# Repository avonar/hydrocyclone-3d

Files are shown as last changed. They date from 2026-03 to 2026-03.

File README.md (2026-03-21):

# Hydrocyclone Prototype

This repository contains a parametric `OpenSCAD` prototype of a small household hydrocyclone / centrifugal sand separator intended as a pre-filter for well water.

The current concept is aimed at:

- `1-3 m^3/h` operating range, with `2.5 m^3/h` as the main design point
- `2-4 bar` system pressure
- `32 mm` external pipe connections
- sand and coarse suspended solids removal before a downstream filter

This is a geometry and assembly prototype, not a certified pressure vessel.

## Design Intent

The project is based on a hybrid engineering model:

- the upper part behaves like a compact hydrocyclone
- the lower part is treated as a straight underflow outlet for connection to a separate sediment collector / purge volume

Current base proportions:

- cyclone chamber diameter `Dc = 40 mm`
- cylindrical section height `Hc = 40 mm`
- cone length `Lc = 120 mm`
- vortex finder inner diameter `Do = 14 mm`
- lower outlet diameter `Du = 9 mm`
- minimum wall thickness `t = 4 mm`

The inlet is modeled as:

- external round `32 mm` stub
- internal transition to a short tangential slot

The top assembly is split into two printable parts:

- main body
- removable lid/head with the outlet stub and internal vortex finder

This split reduces support material and makes the upper internal geometry printable.

## Repository Layout

- [hydrocyclone_concept.scad](/Users/avonar/petprojects/hydrocyclone_v2/hydrocyclone_concept.scad)  
  Main source of truth for the current 3D geometry.

- [hydrocyclone_inlet_vertical_section_debug.scad](/Users/avonar/petprojects/hydrocyclone_v2/hydrocyclone_inlet_vertical_section_debug.scad)  
  Validation cut through the inlet plane. Useful for checking the inlet window and vortex finder depth relationship.

- [hydrocyclone_lid_section_debug.scad](/Users/avonar/petprojects/hydrocyclone_v2/hydrocyclone_lid_section_debug.scad)  
  Validation cut for the removable lid and inner outlet tube.

- [Makefile](/Users/avonar/petprojects/hydrocyclone_v2/Makefile)  
  Rebuilds printable artifacts and debug sections.

Generated files are written into `artifacts/`.

## Build

Requirements:

- `openscad`
- `magick` (ImageMagick) for `svg -> png` conversion

Common commands:

```bash
make -j all
```

Builds:

- body `STL`
- lid `STL`
- body `3MF`
- lid `3MF`
- assembly preview `STL`
- validation section `SVG` and `PNG` files

Other useful targets:

```bash
make -j prints
make -j validate
make preview
make print3mf
make clean
```

`Makefile` is intentionally structured so that `make -j ...` can run independent OpenSCAD renders in parallel.

## Current Outputs

After a successful build, the main outputs are:

- `artifacts/hydrocyclone_body_print.stl`
- `artifacts/hydrocyclone_lid_print.stl`
- `artifacts/hydrocyclone_body_print.3mf`
- `artifacts/hydrocyclone_lid_print.3mf`
- `artifacts/hydrocyclone_concept_preview.stl`

Validation outputs:

- `artifacts/hydrocyclone_inlet_vertical_section_debug.svg`
- `artifacts/hydrocyclone_inlet_vertical_section_debug.png`
- `artifacts/hydrocyclone_lid_section_debug.svg`
- `artifacts/hydrocyclone_lid_section_debug.png`

## Notes On Validation

Two validation cuts are kept in the repository on purpose:

- inlet section: checks whether the vortex finder extends low enough relative to the inlet opening
- lid section: checks whether the inner outlet tube is actually supported by the lid geometry

These are the two checks that are most likely to catch future geometry regressions.

## Safety

This model should be treated as a prototype for:

- fit checks
- printability checks
- assembly checks
- early hydraulic layout validation

It should not be treated as a production-ready pressurized component without:

- material verification
- wall / joint verification
- sealing design validation
- hydrostatic testing
- safety margin review

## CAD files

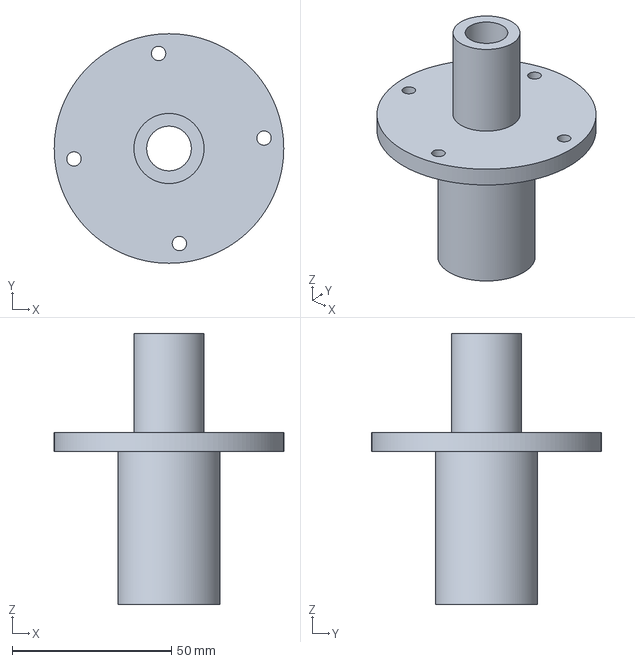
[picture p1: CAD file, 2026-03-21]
artifacts/hydrocyclone_lid_print.3mf
72.0 x 72.0 x 85.0 mm

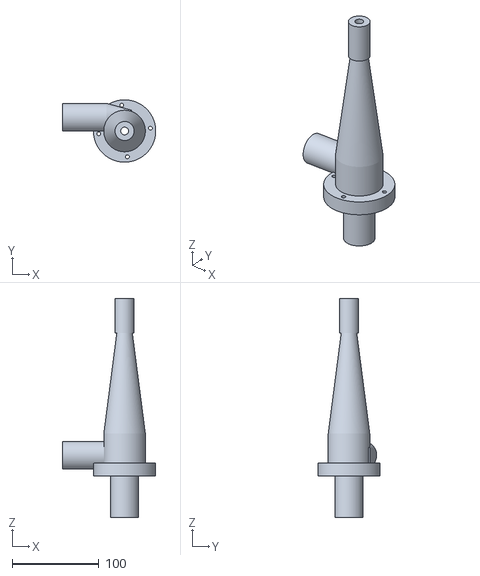
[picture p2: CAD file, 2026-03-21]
artifacts/hydrocyclone_concept_preview.stl
108.0 x 72.0 x 253.0

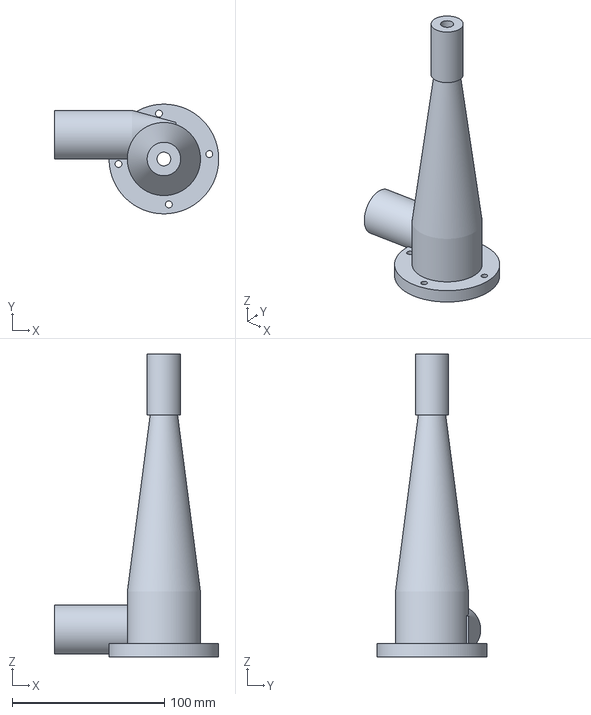
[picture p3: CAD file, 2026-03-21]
artifacts/hydrocyclone_body_print.3mf
108.0 x 72.0 x 199.0 mm

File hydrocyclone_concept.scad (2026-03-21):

$fn = 128;
render_mode = is_undef(render_mode) ? "assembly" : render_mode;

// Parametric hydrocyclone concept for layout and 3D-print iteration.
// Units: millimeters.
// This is a geometry study model, not a certified pressure vessel.

dc = 40; // Inner diameter of cylindrical vortex chamber
hc = 40; // Height of cylindrical vortex chamber
lc = 120; // Cone length
do_inner = 14; // Vortex finder inner diameter
vf_insert = 16; // Vortex finder insertion depth below the removable lid
du = 9; // Lower outlet diameter
bottom_stub_len = 36; // Lower straight outlet for connection to a separate collector
bottom_stub_od = 22; // Outer diameter of the lower outlet stub

wall = 4; // Minimum wall thickness
top_cap = 6; // Removable lid thickness
flange_thickness = 6; // Body flange thickness at the split line
join_overlap = 2; // Solid overlap so boolean unions stay connected
port_overlap = 4; // Extra overlap for bores so they remain visibly through
vf_outer_od = do_inner + 2 * wall; // Solid inner sleeve diameter of the vortex finder

outlet_stub_len = 48; // Straight outlet stub above the removable lid
outlet_stub_od = 32; // Outer diameter of outlet stub
outlet_stub_id = 26; // Bore for top outlet connection
outlet_transition_len = 14; // Internal transition length from the 32 mm connector bore to the vortex finder

inlet_pipe_od = 32; // External connection sized for a 32 mm pipe
inlet_pipe_id = 26; // Approximate bore for a 32 mm PE/PND pipe connection
inlet_slot_w = 8; // Tangential slot width at the chamber wall
inlet_slot_h = 10; // Tangential slot height
inlet_outer_slot_w = inlet_slot_w + 2 * wall;
inlet_outer_slot_h = inlet_slot_h + 2 * wall;
inlet_stub_len = 48; // Straight external pipe length before the transition
inlet_transition_len = 22; // Reducer length from the pipe connection to the nozzle
inlet_body_penetration = 8; // Outer reducer penetration into the main body for a true union
inlet_nozzle_intrusion = 4; // Inner flow penetration into the chamber
inlet_z = 10; // Lower Z of the tangential slot from the open chamber top

flange_od = 72; // Outer diameter of the split flange for the printable body/lid joint
flange_hole_d = 4.5; // Through holes for M4 hardware
flange_hole_count = 4; // Bolt count around the flange
flange_bcd = 60; // Bolt circle diameter
bolt_angle_offset = 6.25; // Rotate the bolt pattern away from the inlet stub without moving the next hole under the opposite pipe

outer_dc = dc + 2 * wall;
outer_du = du + 2 * wall;

cone_z = hc;
bottom_stub_z = cone_z + lc;
inlet_outer_slot_center_y = outer_dc / 2 - inlet_outer_slot_w / 2;
inlet_slot_center_y = dc / 2 - inlet_slot_w / 2;
inlet_pipe_center_y = inlet_outer_slot_center_y;
inlet_center_z = inlet_z + inlet_slot_h / 2;
split_raise = max(2, inlet_pipe_od / 2 - inlet_center_z + 2); // Lift the split plane above the round inlet crown
vf_tip_margin_below_inlet = 8; // Push the vortex finder tip clearly below the inlet window to reduce short-circuit flow
vf_insert_min_visible = inlet_z + inlet_slot_h + split_raise + vf_tip_margin_below_inlet; // Keep the vortex finder tip below the inlet opening when viewed from the feed side
vf_insert_effective = max(vf_insert, vf_insert_min_visible);

module bolt_holes(z0, h) {
  for (i = [0:flange_hole_count - 1])
    rotate([0, 0, bolt_angle_offset + i * 360 / flange_hole_count])
      translate([flange_bcd / 2, 0, z0])
        cylinder(h=h, d=flange_hole_d);
}

module inlet_outer_manifold() {
  union() {
    translate([-inlet_stub_len - inlet_transition_len - join_overlap, inlet_pipe_center_y, inlet_center_z])
      rotate([0, 90, 0])
        cylinder(h=inlet_stub_len + join_overlap, d=inlet_pipe_od);

    hull() {
      translate([-inlet_transition_len - join_overlap, inlet_pipe_center_y, inlet_center_z])
        rotate([0, 90, 0])
          cylinder(h=1 + join_overlap, d=inlet_pipe_od);
      translate(
        [
          inlet_body_penetration - 1,
          inlet_outer_slot_center_y - inlet_outer_slot_w / 2,
          inlet_z - wall,
        ]
      )
        cube([1, inlet_outer_slot_w, inlet_outer_slot_h]);
    }
  }
}

module inlet_flow_volume() {
  union() {
    translate([-inlet_stub_len - inlet_transition_len - join_overlap - 1, inlet_pipe_center_y, inlet_center_z])
      rotate([0, 90, 0])
        cylinder(h=inlet_stub_len + join_overlap + 1, d=inlet_pipe_id);

    hull() {
      translate([-inlet_transition_len - join_overlap, inlet_pipe_center_y, inlet_center_z])
        rotate([0, 90, 0])
          cylinder(h=1 + join_overlap, d=inlet_pipe_id);
      translate(
        [
          0,
          inlet_slot_center_y - inlet_slot_w / 2,
          inlet_z,
        ]
      )
        cube([1, inlet_slot_w, inlet_slot_h]);
    }

    // Shape the final slot opening by the chamber radius instead of a flat nozzle end.
    intersection() {
      translate(
        [
          -1,
          inlet_slot_center_y - inlet_slot_w / 2,
          inlet_z,
        ]
      )
        cube([inlet_nozzle_intrusion + 1, inlet_slot_w, inlet_slot_h]);
      translate([0, 0, -join_overlap])
        cylinder(h=hc + 2 * join_overlap, d=dc);
    }
  }
}

module body_outer_shell() {
  union() {
    translate([0, 0, -split_raise])
      cylinder(h=flange_thickness + split_raise, d=flange_od);
    translate([0, 0, -split_raise])
      cylinder(h=hc + split_raise, d=outer_dc);
    translate([0, 0, cone_z])
      cylinder(h=lc, d1=outer_dc, d2=outer_du);
    translate([0, 0, bottom_stub_z - port_overlap])
      cylinder(h=bottom_stub_len + port_overlap, d=bottom_stub_od);

    inlet_outer_manifold();
  }
}

module body_flow_volume() {
  union() {
    translate([0, 0, -split_raise - 1])
      cylinder(h=hc + split_raise + 1, d=dc);
    translate([0, 0, cone_z])
      cylinder(h=lc, d1=dc, d2=du);
    translate([0, 0, bottom_stub_z - port_overlap])
      cylinder(h=bottom_stub_len + wall + port_overlap, d=du);

    inlet_flow_volume();
    bolt_holes(-split_raise - 1, flange_thickness + split_raise + 2);
  }
}

module lid_outer_shell() {
  union() {
    translate([0, 0, -split_raise - top_cap])
      cylinder(h=top_cap, d=flange_od);
    translate([0, 0, -split_raise - top_cap - outlet_stub_len])
      cylinder(h=outlet_stub_len + port_overlap, d=outlet_stub_od);
    translate([0, 0, -split_raise - top_cap])
      cylinder(h=top_cap + vf_insert_effective, d=vf_outer_od);
  }
}

module lid_flow_volume() {
  union() {
    translate([0, 0, -split_raise - top_cap - outlet_stub_len - port_overlap - 1])
      cylinder(h=outlet_stub_len + top_cap + port_overlap + 1 - outlet_transition_len, d=outlet_stub_id);
    translate([0, 0, -split_raise - outlet_transition_len])
      cylinder(h=outlet_transition_len, d1=outlet_stub_id, d2=do_inner);
    translate([0, 0, -split_raise - port_overlap])
      cylinder(h=vf_insert_effective + port_overlap, d=do_inner);

    bolt_holes(-split_raise - top_cap - 1, top_cap + 2);
  }
}

module hydrocyclone_body_part() {
  difference() {
    body_outer_shell();
    body_flow_volume();
  }
}

module hydrocyclone_lid_part() {
  difference() {
    lid_outer_shell();
    lid_flow_volume();
  }
}

module hydrocyclone_assembly() {
  hydrocyclone_body_part();
  hydrocyclone_lid_part();
}

module hydrocyclone_exploded() {
  hydrocyclone_body_part();
  translate([0, 0, -split_raise - top_cap - 12])
    hydrocyclone_lid_part();
}

if (render_mode == "none")
  ;
else if (render_mode == "body")
  hydrocyclone_body_part();
else if (render_mode == "lid")
  hydrocyclone_lid_part();
else if (render_mode == "exploded")
  hydrocyclone_exploded();
else
  hydrocyclone_assembly();

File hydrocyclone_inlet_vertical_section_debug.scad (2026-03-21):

use <hydrocyclone_concept.scad>

// XZ section through the inlet centerline of the current assembly.
// This file intentionally mirrors only the cut-plane position so the geometry comes from the main model.

inlet_pipe_center_y = 16;

projection(cut = true)
  translate([0, 0, -inlet_pipe_center_y])
    rotate([90, 0, 0])
      hydrocyclone_assembly();

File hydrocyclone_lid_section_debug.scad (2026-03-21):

use <hydrocyclone_concept.scad>

projection(cut = true)
    rotate([90, 0, 0])
        hydrocyclone_lid_part();

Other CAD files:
artifacts/hydrocyclone_body_print.stl
artifacts/hydrocyclone_lid_print.stl

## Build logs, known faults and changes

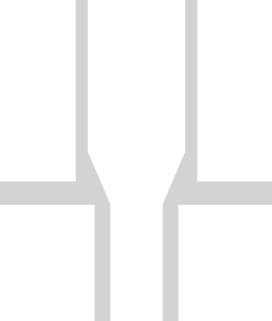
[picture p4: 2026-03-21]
artifacts/hydrocyclone_lid_section_debug.png

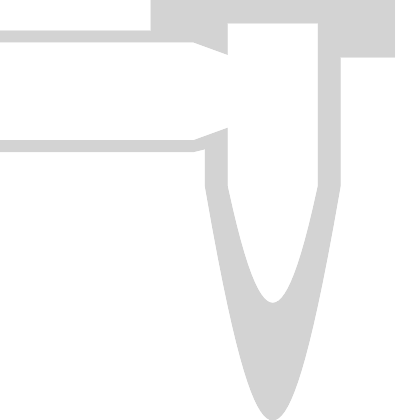
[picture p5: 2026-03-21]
artifacts/hydrocyclone_inlet_vertical_section_debug.png
